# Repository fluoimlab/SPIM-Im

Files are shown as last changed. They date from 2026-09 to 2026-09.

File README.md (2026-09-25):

Stand With Ukraine (https://stand-with-ukraine.pp.ua)

Selective Plane Illumination Microscope
================================

_Fluorescence Imaging Laboratory, Kyiv, Ukraine_

<p align="center">
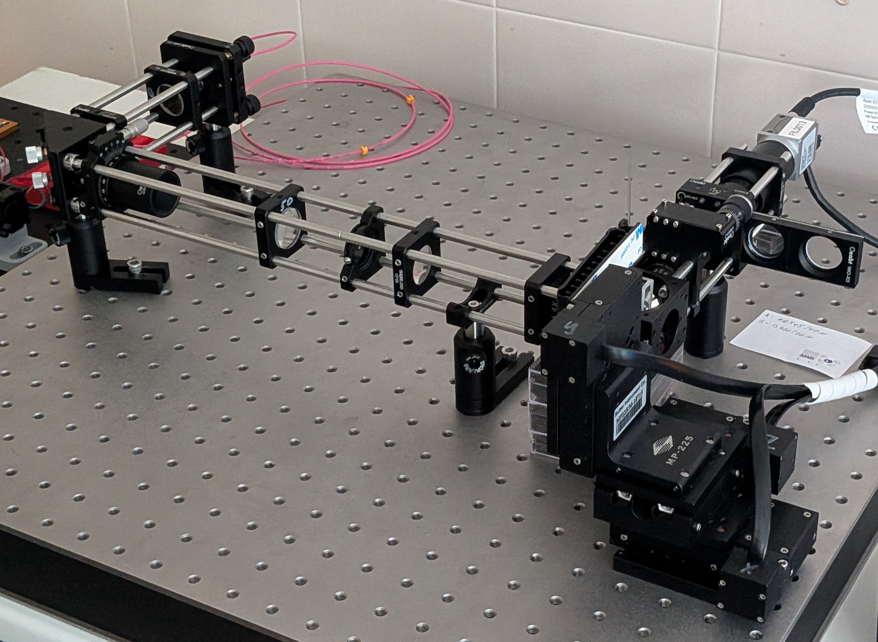
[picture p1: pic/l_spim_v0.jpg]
</a>
</p>
__L-SPIM v0__

# L-SPIM v0 parameters overview

| Parameter | Value |
| --- | --- |
| Detection objective | Olympus PlaN 10x 0.25 |
| Magnification | 5.56x (F100) or 6.94x (F125) |
| Camera | Basler Ace 2R Pro (a2A5320-23umPRO), 5320x3032 px (16.1 Mpx) |
| Pixel size | 0.493 μm/px (F100) or 0.395 μm/px (F125) |
| Field of view | 2.62x1.49 mm (F100) or 2.1x1.2 mm (F125) |
| Z-stack step resolution | 16 μstep/μm (0.0625 μm/μstep) |
| Lateral resolution, FWHM theoretical/estimated | 1.12 μm/2.06 μm |
| Axial resolution, FWHM theoretical/estimated | 11.70 μm/ 6.32 μm |
| Excitation lasers | 510 nm, 640 nm |
| Emission filters | Chroma HQ545/40m, Chroma D620/20m, Chroma HQ700/75m |

# Detection arm

## Detection params
| Parameter | Value |
| --- | --- |
| Detection objective | Olympus PlaN 10x 0.25 FN 22 (F18) |
| Detection tube lens | F100 or F125 |
| Magnification | 5.56x or 6.94x |
| Camera | Basler Ace 2R Pro (a2A5320-23umPRO) |
| Pixel size | 0.493 μm/px or 0.395 μm/px |
| Field of view | 2.62x1.49 mm or 2.1x1.2 mm |
| Theoretical resolution (500 nm) | 1.220 μm |
| Theoretical depth of field (500 nm, n=1.33) | 10.640 μm |
| Estimated resolution FWHM (F100) | 2.06 μm |
| Estimated depth of field FWHM (F100) | 6.32 μm |
| Z-stack step (Sutter Instruments MPC-200 with MP225/M) | 0.0625 μm/μstep (16 μstep/μm) |

## Filters

# Excitation arm
## Light path
Illumination objective 4x (F45)

Full FOV light sheet parameters:
- __Tubus lens F125__
FOV high 2.1 mm => d = 2.1 => $NA_{ill}$ = d / 2f = 2.1/(2*45) = 0.023

$x_{ls} \approx \frac{2 n \lambda}{\pi NA_{ill}^2} = \frac{2 * 1.33 * 510}{3.14 * 0.023^2} = 817 \mu m$

$z_{ls} \approx \frac{2 \lambda}{\pi NA_{ill}} = \frac{2 * 510}{3.14 * 0.023} = 14.1 \mu m$

## Lasers power

- 510 nm: 2.2 mW in imaging chamber
- 640 nm: 1.2 mW in imaging chamber

# Control software
## Micromanager configuration

## Camera
| Model | Basler Ace 2R |
| --- | --- |
| ID | a2A5320-23umPRO |
| Sensor | Sony IMX542 (CMOS) |
| Sensor size | 14.58x8.31 mm (1.1") |
| Sensor diagonal | 16.78 mm |
| Pixels (HxV) | 5320x3032 (16.1 Mpx) |
| Pixel size | 2.74x2.74 μm |
| Frame rate | up to 24 fps |

### GPIO pinout

|Pin|Function|I/O Line|Colour|
|-|-|-|-|
|1|12–24 VDC camera power|-|Brown|
|2|Opto-coupled I/O input line|Line 1|White|
|3|Ground for opto-coupled I/O line|-|Blue|
|4|General purpose I/O (GPIO) line|__Line 2__|Black|
|5|General purpose I/O (GPIO) line|Line 3|Grey|
|6|Ground for camera power and General Purpose I/O (GPIO) lines|-|Pink|

[Basler Power-I/O Cable](https://docs.baslerweb.com/basler-power-io-cable-m8-6p-open-p)

### GPIO configuration
Pylon Viewer v7.2 camera parameters, category __Digital I/O Control__:

- __Line Selector:__ Line 2
- __Line Inverter:__ not selected
- __Line Mode:__ Output
- __Line Source:__ Exposure Active

<p align="center">
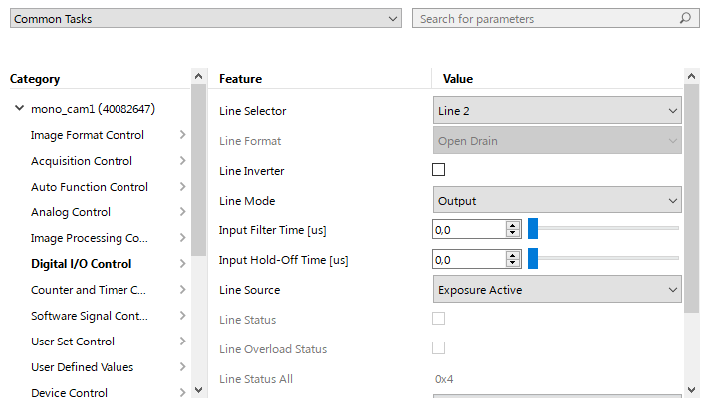
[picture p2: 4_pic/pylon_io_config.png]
</a>
</p>

## Sync
### ArdiunoMM
- Bauderate: 57600
- Responce timeout: 2000 ms

### Arduino32Bit (deprecated)
Synchronisation with [Arduino32bitBoards](https://micro-manager.org/Arduino32bitBoards), specs for ESP32:

- Baudrate: 115200
- Laser TTL trigger module requires 5V, need level conversion 3.3V -> 5V

__Pinout:__
- Trigger: __Pin 5 - camera Line 2 input__
- Channel 1 (index 0): __Pin 25/DAC - Level Converter ON__
- Channel 2 (index 1): __Pin 26/DAC - 510 nm trigger__
- Channel 3 (index 2): __Pin 27/PWM - 640 nm trigger__
- Channel 4 (index 3): Pin 15/PWM
- Channel 5 (index 4): Pin 14/PWM
- Channel 6 (index 5): Pin 4/PWM
- Channel 7 (index 6): Pin 23/PWM
- Channel 8 (index 7): Pin 19/PWM

__Decimal switch state value for ON is 2^index.__

__Switch states__
|State|Pin Hight|State|
|-|-|-|
|Level Converter ON|25|1|
|510 nm|25+26 (Ch.1+Ch.2)|1+2=__3__|
|640 nm|25+27 (Ch.1+Ch.3)|1+4=__5__|
|510 nm + 640 nm|25+26+27 (Ch.1+Ch.2+Ch.3)|1+2+4=__7__|

# License 
This open-source project is released under the CERN Open Hardware License. Our aims are to promote open scientific hardware development and to share our engineering solutions.

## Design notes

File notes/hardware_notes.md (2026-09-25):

# Hardware notes
- ESP32 with [Arduino32bitBoards device adapter](https://github.com/bonnom/Arduino32BitBoards/tree/master?tab=readme-ov-file)
- OXLaser 510 nm 50 mW, and 620 nm 100 mW
- Basler Ace 2R Pro / Pointgrey Grasshopper 3

## Illumination light path parameters

## Detection objectives

| Model | Olympus PlaN | Olympus UPlanFl Ph. 1 |
| --- | --- | --- |
| Magnification (M) | 10x | 10x |
| Numerical aperture (NA) | 0.25 | 0.3 |
| Working distance (WD) | 10.6 mm | 10 mm |
| Focal distance (F) | 18 mm | 18 mm |
| Back focal plane distance (BFP) | N/A | -19.1 mm |
| Field number (FN) | 22 | 26.5 mm |
| Lateral resolution | 1.34 μm | 1.12 μm |
| Parafocal distance (PD) | 45 mm | 65 mm |
| Exit pupil diameter (EP) | 9 mm | 10.8 mm |

## Cameras

| Model | FLIR Grasshopper 3 | Basler Ace 2R |
| --- | --- | --- |
| ID | GS3-U3-23S6M-C | a2A5320-23umPRO |
| Sensor | Sony IMX174 (CMOS) | Sony IMX542 (CMOS) |
| Sensor size | 11.25x7.03 mm (1/1.2") | 14.58x8.31 mm (1.1") |
| Sensor diagonal | 13.4 mm | 16.78 mm |
| Pixels (HxV) | 1920x1200 (2.3 Mpx) | 5320x3032 (16.1 Mpx) |
| Pixel size | 5.86x5.85 μm | 2.74x2.74 μm |
| Frame rate | up to 162 fps | up to 24 fps |

__FLIR Grasshopper 3 GPIO pinout__
<p align="center">
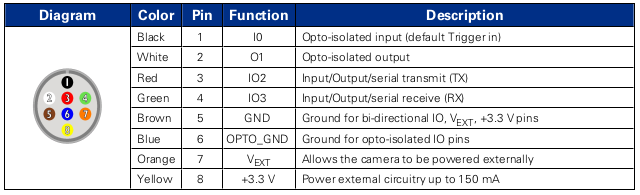
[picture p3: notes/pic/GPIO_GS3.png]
</a>
</p>

__Basler Ace 2R  GPIO pinout__
<p align="center">
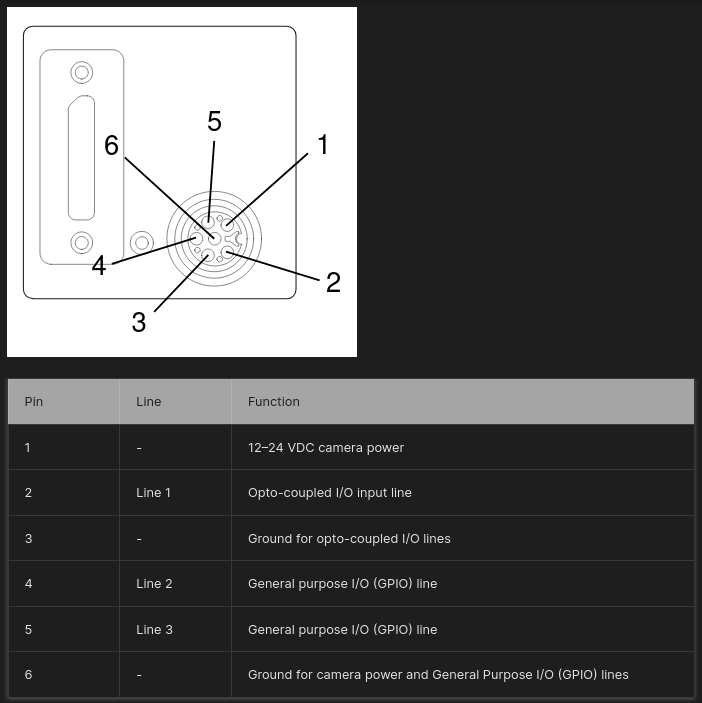
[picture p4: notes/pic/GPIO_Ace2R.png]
</a>
</p>

# Software
All control is provided with [Micro-Manager](https://micro-manager.org/) and [pymmcore-plus](https://pymmcore-plus.github.io/pymmcore-plus/) library with [napari-micromanager](https://pymmcore-plus.github.io/napari-micromanager/) GUI.

__Configuration__
| Component | Desctiption | Micro-manager adapter | Port (laptop)  | Note |
| --- | --- | --- | --- | --- |
| Camera | FLIR Grasshopper3 USB3 | [Point Grey Research](https://micro-manager.org/Point_Grey_Research) | USB 3.0 (COM7) | |
| Stage | Sutter Instruments MPC-200 | [CustomArduino](https://micro-manager.org/CustomArduino) (MarzhauserLStep Z-stage) | | |
| Lasers | Laser control wtih TTL | [Arduino](https://micro-manager.org/Arduino) | COM6 | Change ArduMM version in sketch to 2 |

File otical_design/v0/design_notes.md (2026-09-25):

# Design notes

> [!TIP]
> Read more about the SPIM principles: 
>
> - [Selective Plane Illumination Microscopy](https://link.springer.com/chapter/10.1007/978-0-387-45524-2_37)
> - [openSPIM project](https://openspim.org/)
> - [Selective plane illumination microscopy techniques in developmental biology](https://journals.biologists.com/dev/article/136/12/1963/65234/Selective-plane-illumination-microscopy-techniques)
> - [Using tissue clearing and light sheet fluorescence microscopy for the three-dimensional analysis of sensory and sympathetic nerve endings that innervate bone and dental tissue of mice](https://onlinelibrary.wiley.com/doi/full/10.1002/cne.25582)
> [Olarte et al., 2018](https://opg.optica.org/aop/fulltext.cfm?uri=aop-10-1-111&id=381035)
> [Power and  Huisken, 2017](https://whttps://opg.optica.org/aop/fulltext.cfm?uri=aop-10-1-111&id=381035ww.nature.com/articles/nmeth.4224)

## Gaussian litgh sheet

### Gaussian beam
__Focusing of a Gaussian beam__ (_Power and  Huisken, 2022_)
<p align="center">
</a>
</p>

In paraxial approximation:

```math
\sin \theta \approx \tan \theta \approx \theta
```

Accordng this approximation numerical aperture is equal:
```math
NA = n \sin \theta \approx n \theta 
```

Or for air:
```math
NA = \theta \simeq \frac{d_{beam}}{2 f}
```

The Rayleigh range of the beam and beam waist:

```math
\omega (x_R) = \sqrt{2} \omega_0
```

```math
x_R = \frac{\pi \omega_{0}^{2}}{\lambda}
```

Static light sheet thickness:

```math
\theta = \frac{\pi \omega_{0}}{\lambda} \Rightarrow  \omega_0 = \frac{2 f \lambda}{\pi d_{beam}} \Rightarrow z_{ls} = 2 \omega_0 = \frac{4 f \lambda}{\pi d_{beam}}
```

Static light sheet length:

```math
x_R = \frac{\pi \omega_{0}^{2}}{\lambda} \Rightarrow x_R = \frac{4 f^2 \lambda}{\pi d_{beam}^2} \Rightarrow x_{ls} = 2 x_{R} = \frac{8 f^2 \lambda}{\pi d_{beam}^2}
```

### Illumination system
__Relayed generation of a well-corrected static light sheet__ (_Huisken et al., 2004_)
<p align="center">
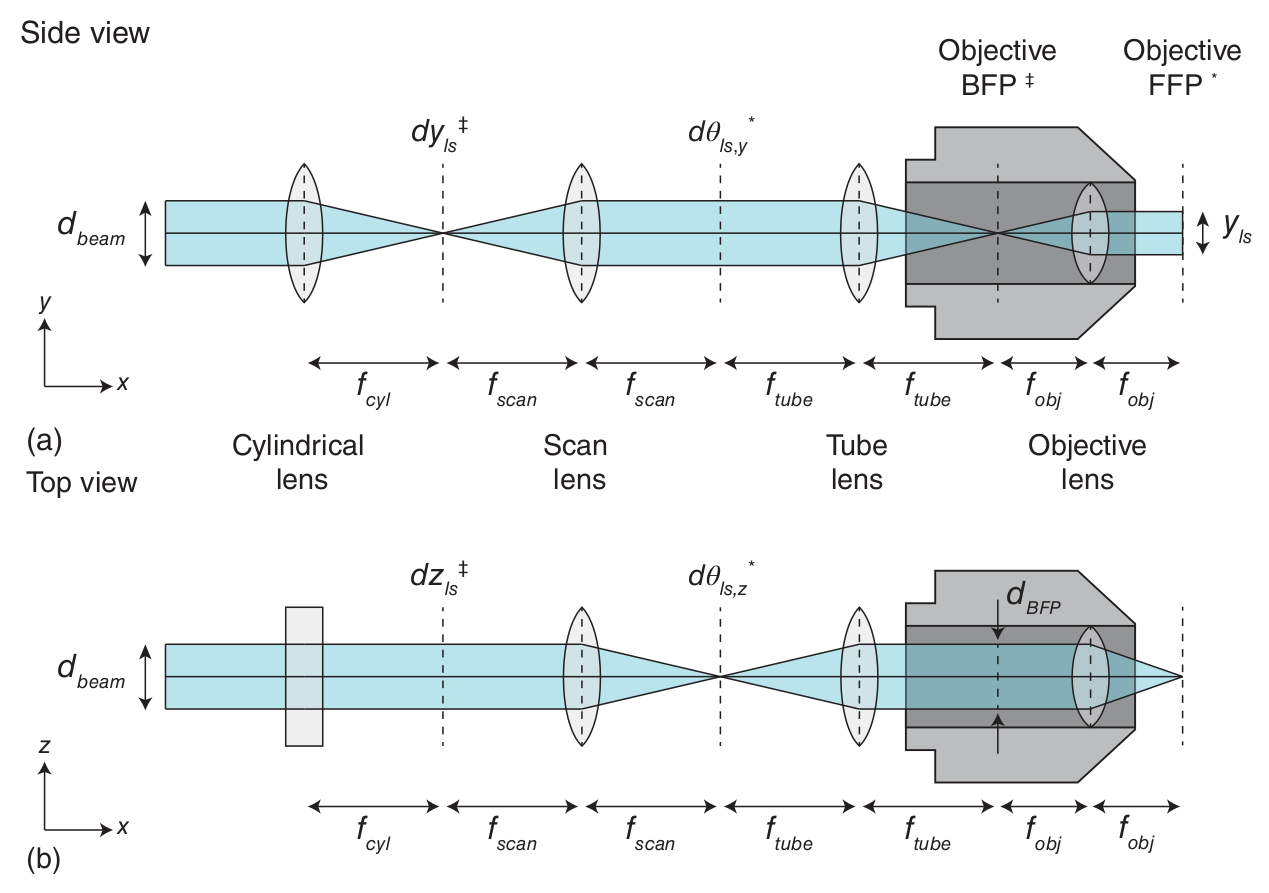
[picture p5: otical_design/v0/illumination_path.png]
</a>
</p>

Objective focal length ($f_{ref}$ for Olympus 180 mm):

```math
f_{front} = n_{imm} f_{back}
```

```math
f_{obj} = f_{back} = \frac{f_{ref}}{M}
```

```math
d_{BFP} = d_{beam} \frac{f_{tube}}{f_{scan}}
```

Illumination NA:

```math
NA_{ill} = n_{imm} \theta = \frac{d_{beam} n_{imm}}{2 f_{front}} = \frac{d_{beam}}{2 f_{obj}}
```

Static light sheet parameters:

```math
z_{ls} = \frac{2 \lambda}{\pi NA_{ill}}
```

```math
x_{ls} = \frac{2 n_{imm} \lambda}{\pi NA_{ill}^2}
```

Relay system:

```math
\textbf{Z}_{ls} = z_{ls} \frac{f_{scan}}{f_{tube}} =  \frac{4 f_obj \lambda}{\pi d_{beam}} \cdot \frac{f_{scan}}{f_{tube}}
```

```math
\textbf{X}_{ls} = x_{ls} (\frac{f_{scan}}{f_{tube}})^2 = \frac{8 f_{obj}^2 n_{imm} \lambda}{\pi d_{beam}^2} \cdot (\frac{f_{scan}}{f_{tube}})^2
```

```math
\textbf{Y}_{ls} = \frac{f_{scan}}{f_{cyl}} \frac{f_{obj}}{f_{tube}} d_{beam}
```

## Detection arm
Lateral resolution (Rayleigh criterion):

```math
d_{xy} = \frac{0.61 \cdot \lambda_{det.}}{NA_{det.}}
```

Axial resolution (depth of field/DOF):

```math
d_z = \frac{n \cdot \lambda_{det.}}{NA_{det.}^2}
```

# Samples and desired characteristics

__NB: is 10x NA 0.25 FN 22 enough?__

## Sciatic nerve
- Nerve diameter: 1.5-2 mm
- Nerve length: 5-20 mm
- A-fiber diameter: 1.5 - 10 um 
- C-fiber diameter: 0.5 - 2 um
- Minimal vessel diameter

## Scaffolds
_In progress_

## Characteristics
- FOV ~ 1x2 mm
- Lateral resolution <1.5 um

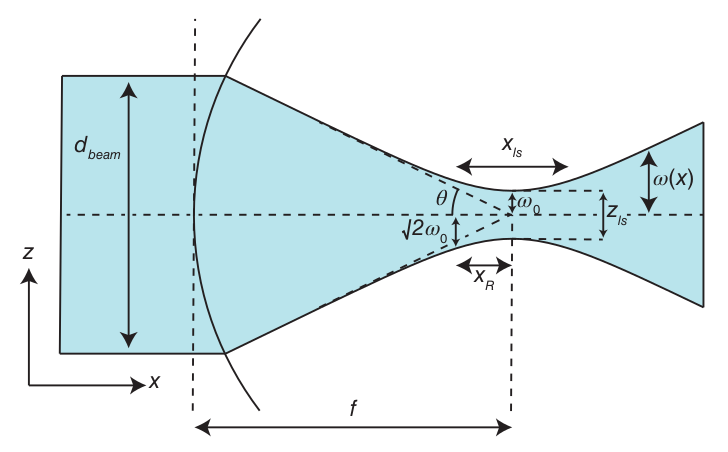
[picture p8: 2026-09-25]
notes/pic/gaussian_beam.png

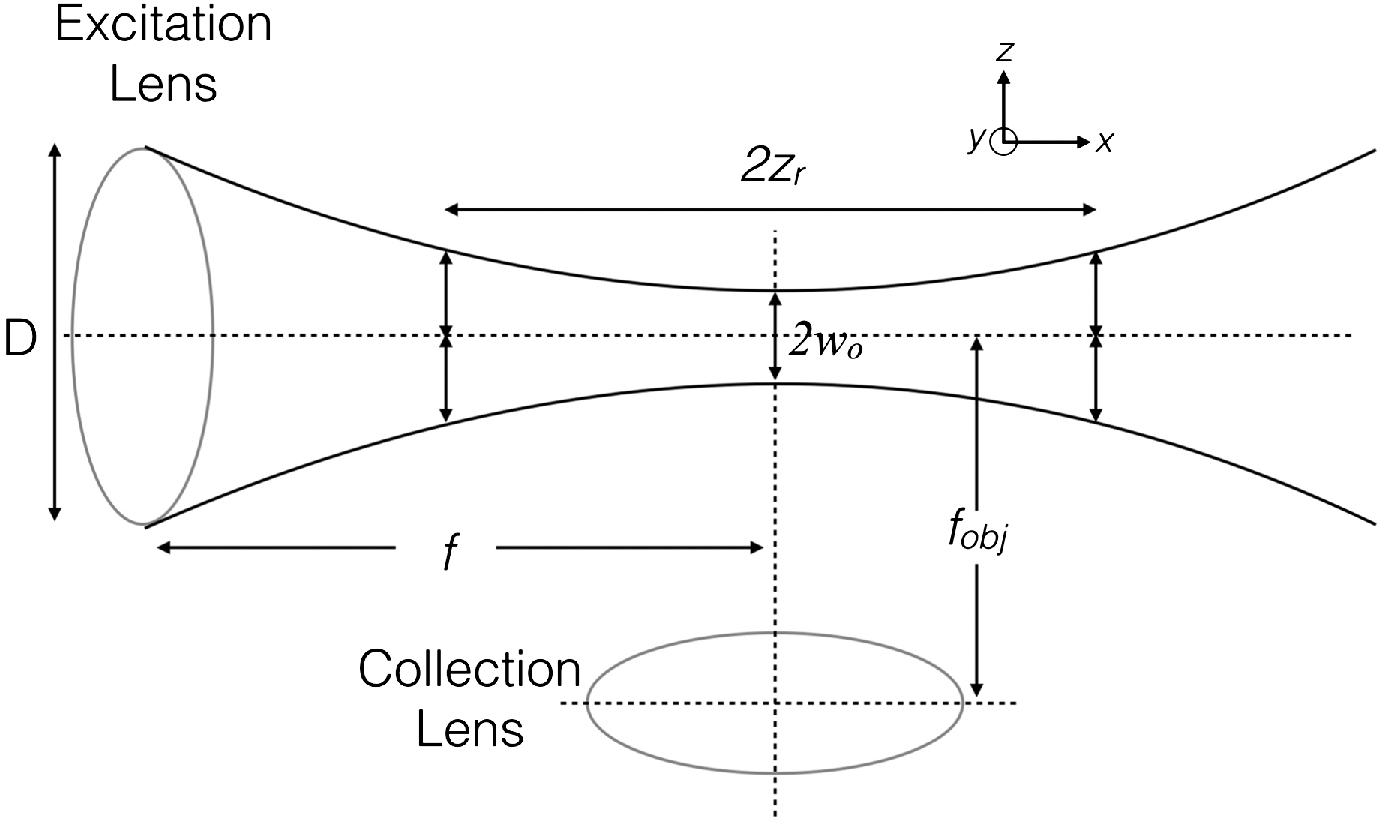
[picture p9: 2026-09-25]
notes/pic/ls_geom_olarte2017.jpeg

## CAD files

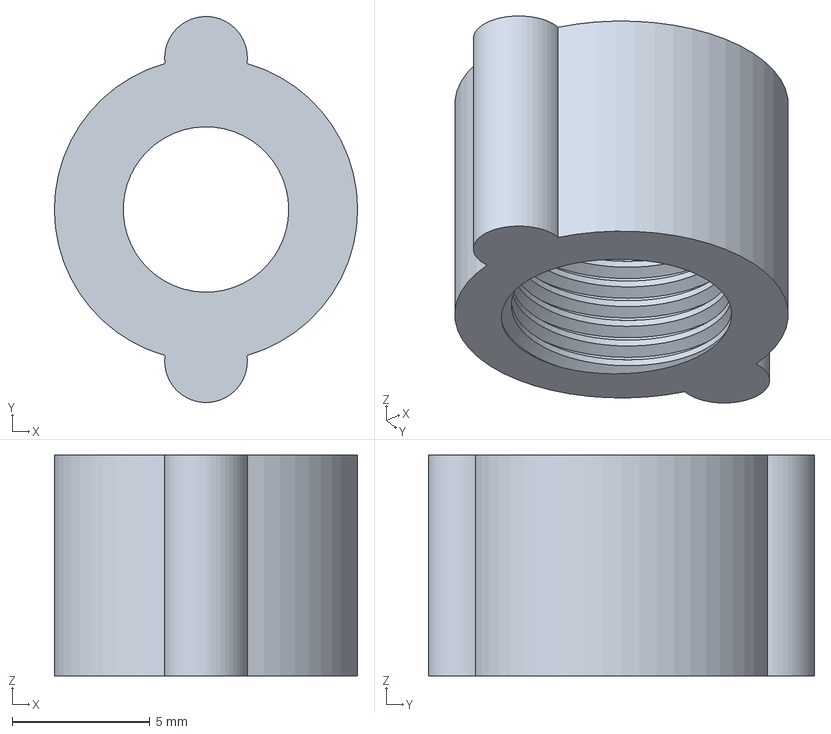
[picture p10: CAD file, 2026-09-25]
models_3D/FC_colimator/FC_single_lens_colimator_v0.FCStd
11.0 x 14.0 x 8.00 mm

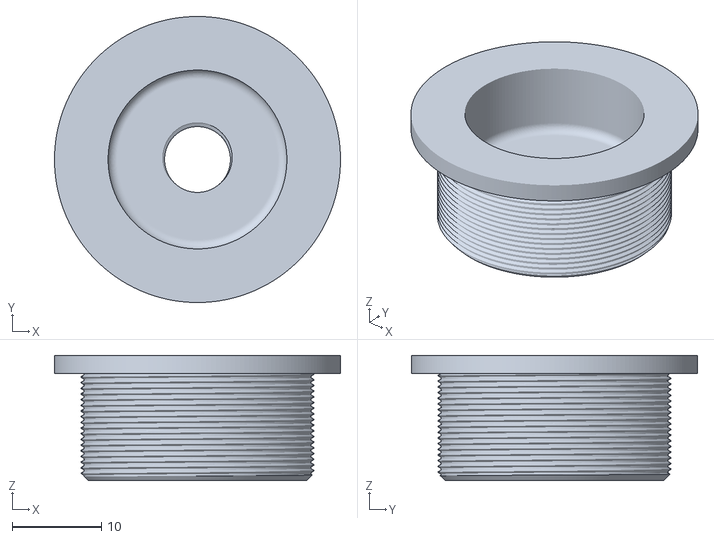
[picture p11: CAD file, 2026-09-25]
models_3D/FC_to_SM1_adapter/Sm1toM8_tolerance04.stl
32.0 x 32.0 x 14.0

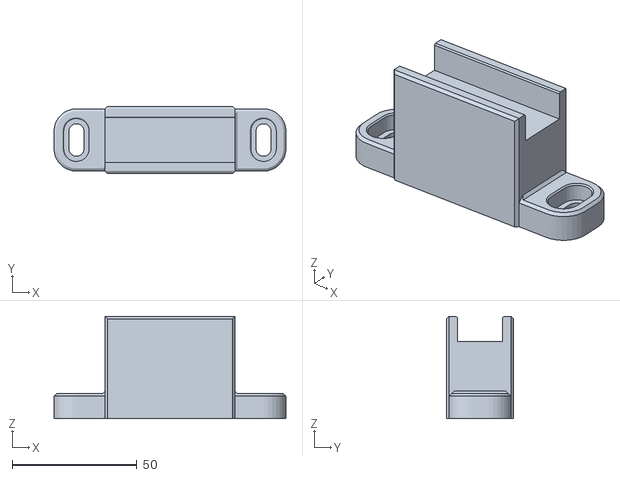
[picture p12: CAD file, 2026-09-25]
models_3D/laser_combiner/0_h40mm_combiner/v2/laserland_620_100mW_h40_25mm_M6_board_v2.stl
93.0 x 27.0 x 41.0

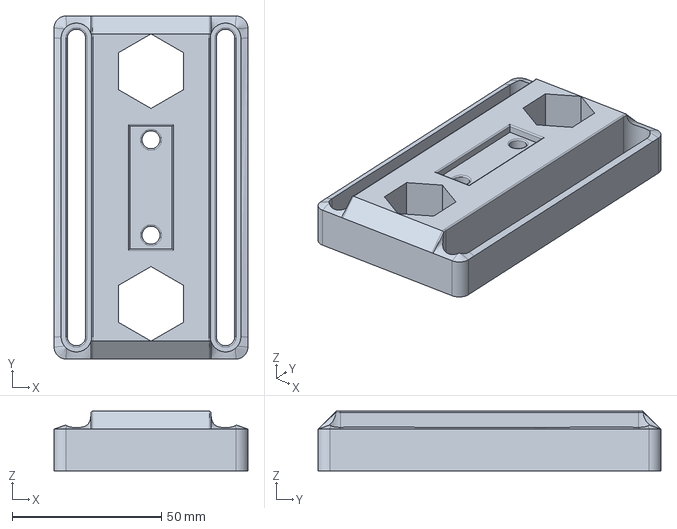
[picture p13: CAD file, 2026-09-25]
models_3D/laser_combiner/breadboard_platform/25mm_M6_platform_v0.FCStd
65.0 x 115.0 x 20.0 mm

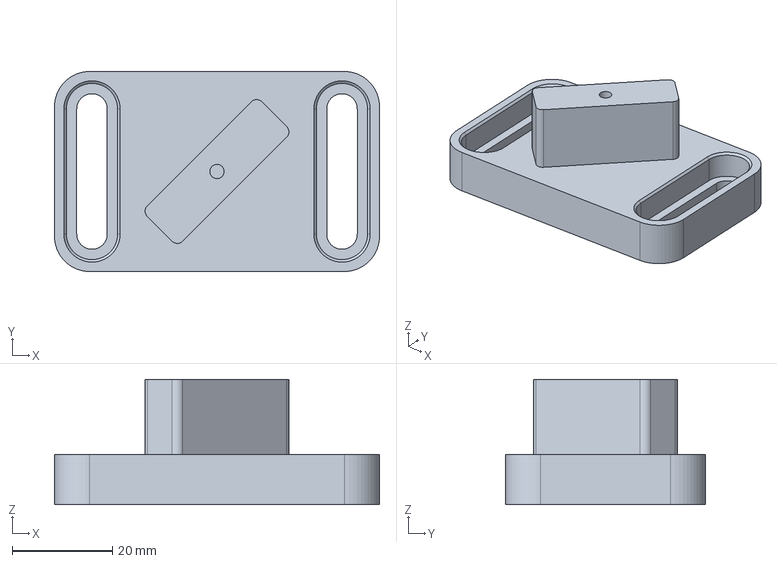
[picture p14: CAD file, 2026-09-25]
models_3D/laser_combiner/kinematic_stand/25mm_M6_stand_v0.FCStd
65.0 x 40.0 x 25.0 mm

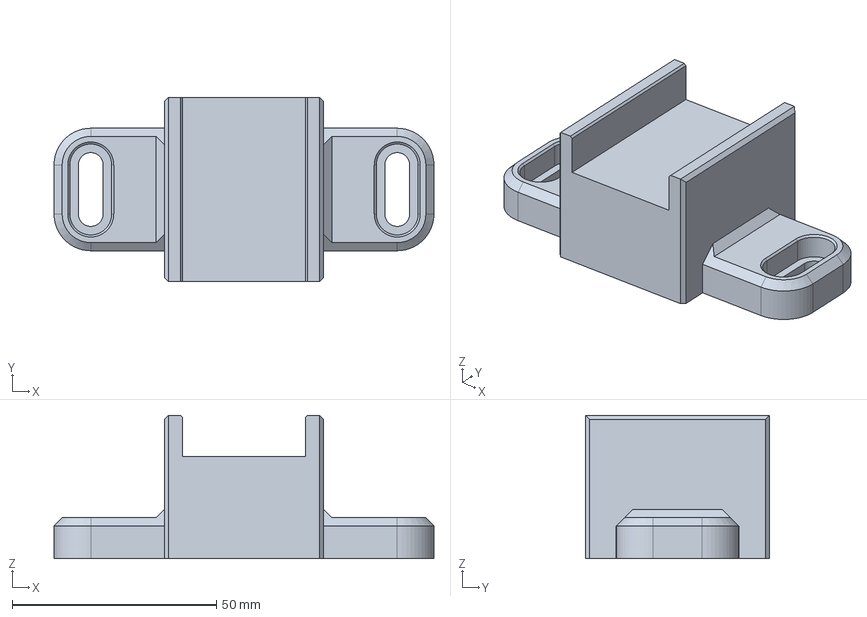
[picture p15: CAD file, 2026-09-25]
models_3D/laser_combiner/laser_breadboard_mount/specific_models/laserland_510nm_50mW_25mm_M6_board_v1.FCStd
93.0 x 45.0 x 35.0 mm

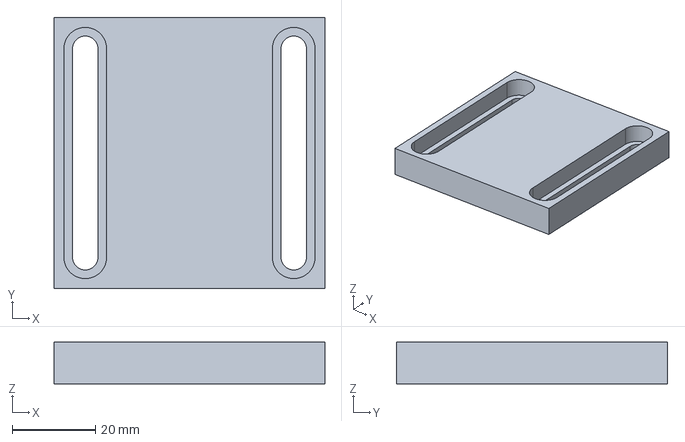
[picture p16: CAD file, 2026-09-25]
models_3D/laser_combiner/laser_combiner_colimator_stand/colimator_stand.FCStd
65.0 x 65.0 x 10.0 mm

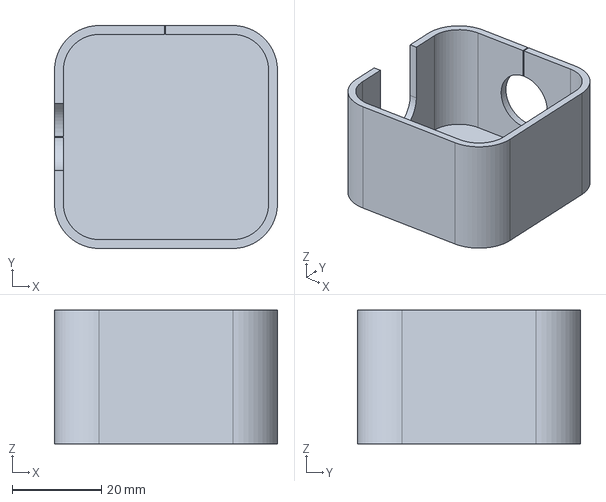
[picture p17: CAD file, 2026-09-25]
models_3D/laser_combiner/laser_combiner_cover/laser_combiner_cover_v1.FCStd
50.0 x 50.0 x 30.0 mm

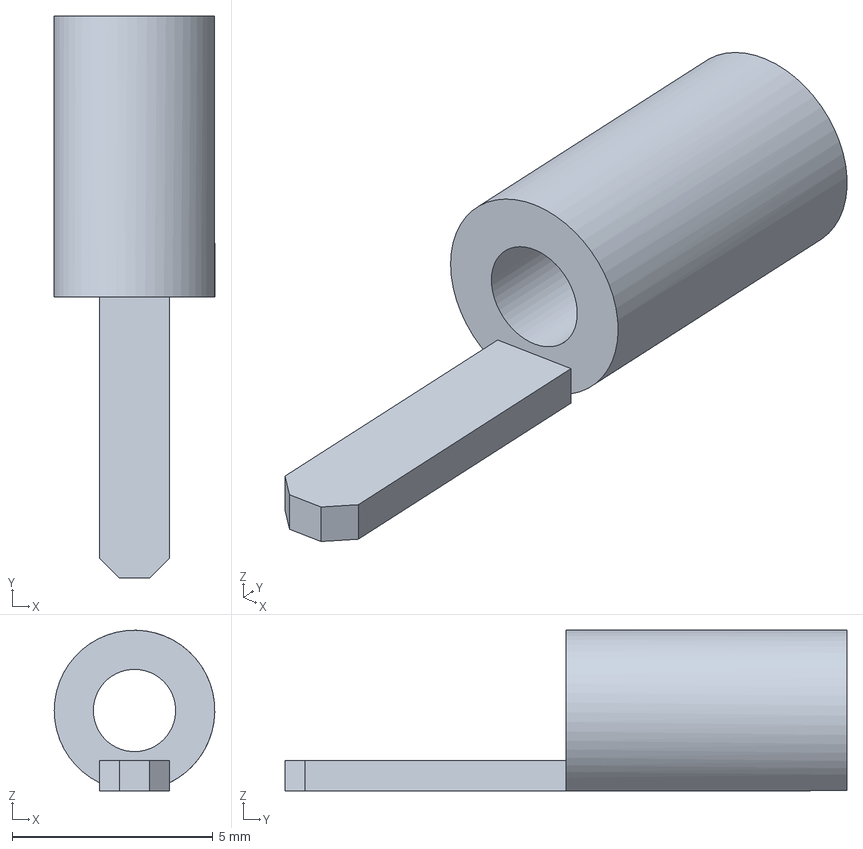
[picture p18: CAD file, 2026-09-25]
models_3D/sample_mounts/simple_narrow_20rod_v0.FCStd
4.00 x 14.0 x 4.00 mm

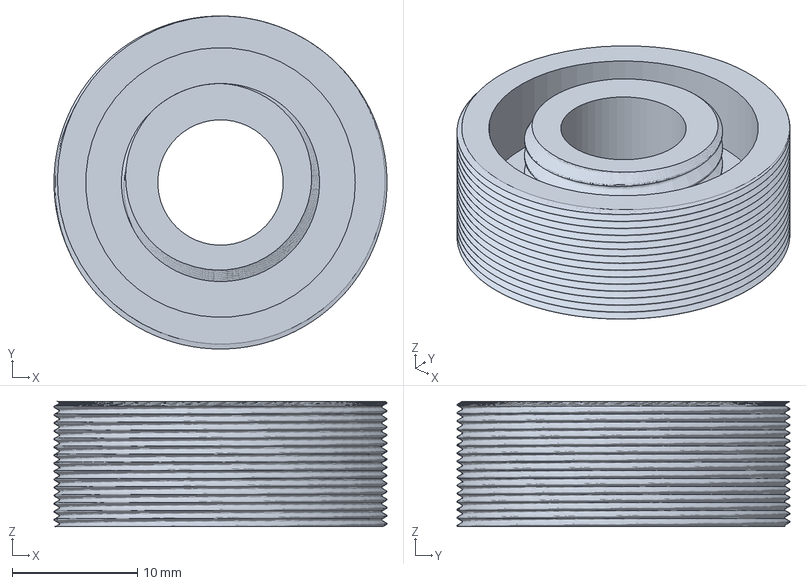
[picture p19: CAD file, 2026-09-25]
models_3D/threads/SM1.FCStd
26.6 x 26.6 x 10.0 mm

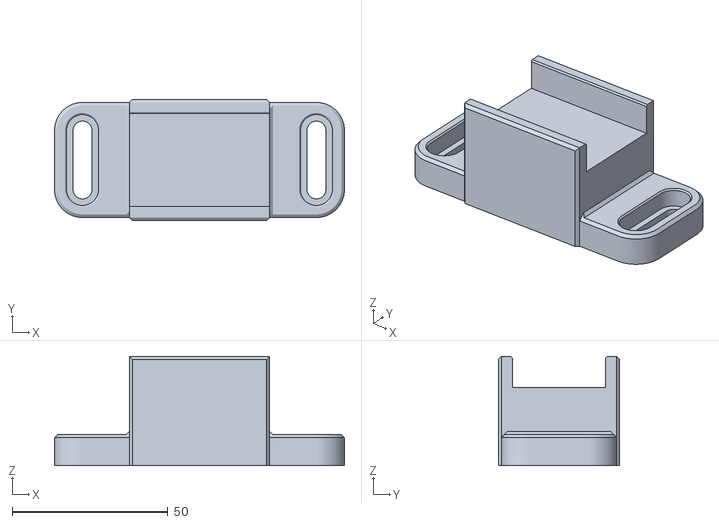
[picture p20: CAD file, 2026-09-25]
models_3D/laser_combiner/0_h40mm_combiner/v2/laserland_510_50mW_h40_25mm_M6_board_v2.stl
93.0 x 38.9 x 35.0

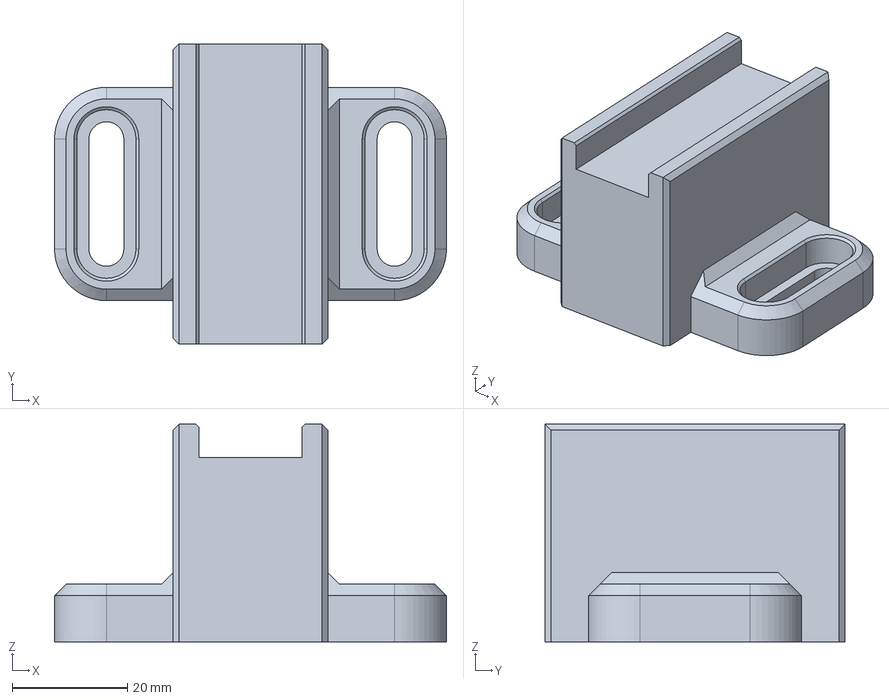
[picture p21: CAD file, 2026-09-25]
models_3D/laser_combiner/laser_breadboard_mount/specific_models/laserland_640nm_100mW_25mm_M6_board_v1.FCStd
68.0 x 52.0 x 37.8 mm

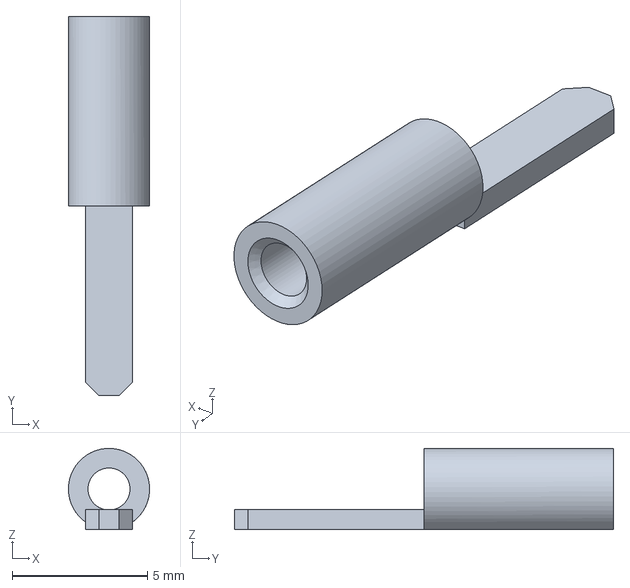
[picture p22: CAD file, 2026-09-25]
models_3D/sample_mounts/simple_narrow_15rod_v0.FCStd
3.00 x 14.0 x 3.00 mm

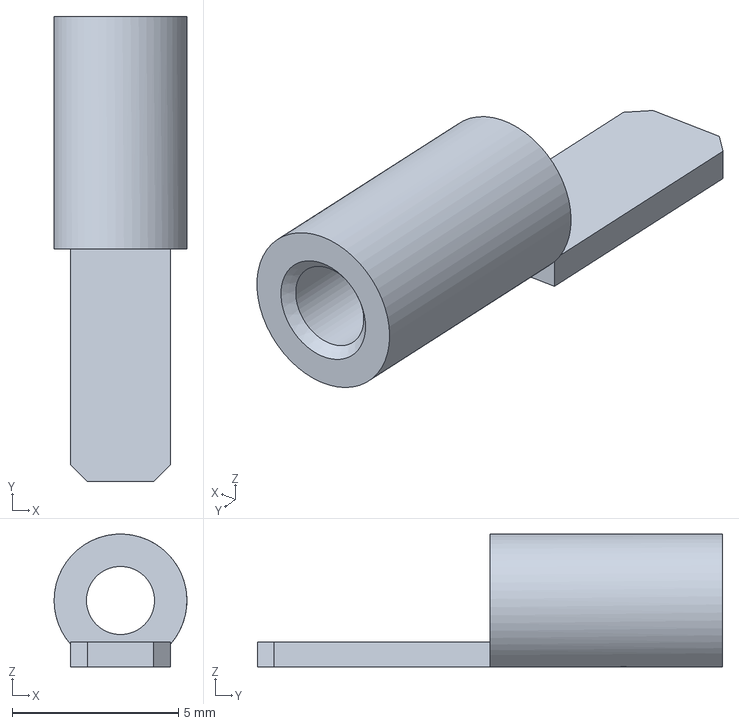
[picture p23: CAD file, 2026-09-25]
models_3D/sample_mounts/simple_20rod_v0.FCStd
4.00 x 14.0 x 4.00 mm

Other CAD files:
models_3D/laser_combiner/laser_combiner_cover/laser_combiner_cover_v1-Body.stl
models_3D/laser_combiner/0_h40mm_combiner/v2/colimator_mount_25mm_M6_platform_v0.stl
models_3D/laser_combiner/laser_breadboard_mount/25mm_M6_board_v2.FCStd
models_3D/laser_combiner/laser_breadboard_mount/specific_models/laserland_505nm_100mW_25mm_M6_board_v1.FCStd
models_3D/FC_colimator/FC_single_lens_colimator_v0.stl
models_3D/laser_combiner/0_h40mm_combiner/v1/dichro_25mm_M6_stand_v0-h40mm.stl
models_3D/laser_combiner/0_h40mm_combiner/v1/dichro_25mm_M6_stand_v1-h40mm.stl
models_3D/laser_combiner/0_h40mm_combiner/v1/laser_505nm_25mm_M6_board_v1-h40.stl
models_3D/laser_combiner/0_h40mm_combiner/v1/laser_510nm_25mm_M6_board_v1-h40mm.stl
models_3D/laser_combiner/0_h40mm_combiner/v1/laser_640nm_25mm_M6_board_v1-h40mm.stl
models_3D/laser_combiner/laser_breadboard_mount/25mm_M6_board_v0.FCStd
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

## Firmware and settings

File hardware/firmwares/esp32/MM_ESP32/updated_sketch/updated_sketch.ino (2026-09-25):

// This is the DAC blanking sketch
// The digital output channels 7 and 8 are replaced with CH1 and CH2
// The voltages for are set in the same way as for other sketches that use a DAC

/*
   First, a serial command can directly set the digital output patern

   Second, a series of patterns can be stored in the arduino and a trigger on pin 2
      wil trigger the consecutive pattern (trigger mode).

   Third, intervals between consecutive patterns can be specified and paterns will be
   generated at these specified time points (timed trigger mode).
*/

/*Interface specifications
    Digital pattern specification: single byte, bit 0 corresponds to pin 8,
      bit 1 to pin 9, etc.. Bits 7 and 8 will not be used (and should stay 0).
*/

/* Set digital output command: 1p
    Where p is the desired digital pattern.

    Controller will return 1 to indicate succesfull execution.
*/

/* Get Digital output command: 2

    Controller will return 2p. Where p is the current digital output pattern
*/

/* Digital output command 3xvv
      Where x is the ouput channel and vv is the output in
      a 12-bbit significant number.

      Controller will return 3xvv
*/

/* Get analogue output: 4
*/

/* Set digital pattern for triggerd mode: 5xd
      Where x is the number of the pattern (currrently, 12 patterns can be stored).
      and d is the digital pattern to be stored at that position. Note that x should be
      real number (i.e., not ASCI encoded)

      Controller will return 5xd
*/

/* Set the Number of digital patterns to be used: 6x
     Where x indicates how many digital patterns will be used (currently, up to 12
     patterns maximum).  In triggered mode, after reaching this many triggers,
     the controller will re-start the sequence with the first pattern.

     Controller will return 6x
*/

/* Skip tirgger: 7x
      Where x indicates how many digital change events on the trigger input pin
      will be ignored.

      Controller will respond with 7x
*/

/* Start trigger mode: 8
      Controller will return 8 to indicate start of trigger mode
      Stop triggered at 9. Trigger mode will supersede (but not stop)
      blanking mode (if it was active)
*/

/* Stop Trigger mode: 9
      Controller will return 9x where x is the number of triggers received during the last
      trigger mode run
*/

/* Set time interval for timed trigger mode: 10xtt
      Where x is the number interval (currently 12 intervals can be stored)
      and tt is the interval (in ms) in Arduino unsigned int format.

      Controller will return 11x
*/

/* Sets how often the timed pattern will be repeated 11x
      This value will be used in timed-trigger mode and sets how often the ouput
      pattern will be repeated.

      Controller will return 11x
*/

/* Starts timed trigger mode: 12
      In timed trigger mode, digital patterns as with function 5 will appear on the
      output pins with intervals (in ms) as set with function 10. After the number of
      patterns set with function 6, the pattern will be repeated for the number of times
      set with function 11. Any input character (which will be processed) will stop
      the pattern generation

      Controller will return 12.
*/

/* Start blanking mode: 20
      In blanking mode, zeroes will be written on the output pins when the trigger pin
      is low, when the trigger pin is high, the pattern set with command 1 will be
      applied to the output pins.

      Controller will return 20
*/

/* Stop blanking mode: 21
      Stopts blanking mode

      Controller returns 21
*/

/* Get Identifcatio: 30
       Returns in ASCI MM-Ard\r\n
*/

/* Get Version: 31
      Returns: version number in ASCI \r\n
*/

/* Read digital state of analog input pins 0-5: 40
      Returns raw value of PINC
*/

/* Read analog state of input pins 0-5: 41x
      x=0-5. Returns analog value as a 10-bit number (0-1023)
*/

/*
   Possible extensions:
     Set and Get Mode (low, change, rising, falling) for trigger mode
     Get digital patterm
     Get Number of digital patterns
*/

unsigned int version_ = 3;

// pin on whick to receive the trigger (2 and 3 can be used with interrupts, although this code does not use them)
// to read out the state of inPin_ faster, ise
// int inPinBit_ = 1<< inPin_; // bit mask

/* TLV5618 configuration
  int dataPin  = 3; // DIN
  int clockPin = 4; // SLCK
  int latchPin = 5; // CS
*/

const int SEQUENCELENGTH = 12 ; //This should be good enough for everybody
byte triggerPattern_[SEQUENCELENGTH]       = {0, 0, 0, 0, 0, 0, 0, 0, 0, 0, 0, 0};
unsigned int triggerDelay_[SEQUENCELENGTH] = {0, 0, 0, 0, 0, 0, 0, 0, 0, 0, 0, 0};
int patternLength_  = 0;
byte repeatPattern_ = 0;
volatile long triggerNr_; // total # of triggers in this run (0-based)
volatile long sequenceNr_; // # of trigger in sequence (0-based)
int skipTriggers_ = 0; // # of triggers to skip before starting to generate patterns
byte currentPattern_ = 0;
const unsigned long timeOut_ = 1000;
bool blanking_ = false;
bool blankOnHigh_ = false;
bool triggerMode_ = false;
boolean triggerState_ = false;


// New additions for rewrite code
byte portbAlt = 0;
byte pindAlt = 0;

// Set the output channnels, these are the ones for most handy for TinyPico
const int inPin_ = 5;
const int ch1 = 25;
const int ch2 = 26;
const int ch3 = 27;
const int ch4 = 15;
const int ch5 = 14;
const int ch6 = 4;
const int ch7 = 23;
const int ch8 = 19;

// Set the input channels for future use
const int a1 = 18;
const int a2 = 22;
const int a3 = 21;
//  const int a4 = 0;
//  const int a5 = 4;


// New additions for use of internal DAC
unsigned int msblsb[] = {255, 255, 255, 255, 255, 255, 255, 255};


// New Additions for use PWM
const int PWMfreq = 10000;
const int PWMresolution = 8;
// const int pwmCh3 = 2;
// const int pwmCh4 = 3;
// const int pwmCh5 = 4;
// const int pwmCh6 = 5;
// const int pwmCh7 = 6;
// const int pwmCh8 = 7;


void setup() {
  // put your setup code here, to run once:
  Serial.begin(115200); //Baud rate

  pinMode(inPin_, INPUT);

  // Setting up pwm
  // ledcAttach(pwmCh3, PWMfreq, PWMresolution);
  // ledcAttach(pwmCh4, PWMfreq, PWMresolution);
  // ledcAttach(pwmCh5, PWMfreq, PWMresolution);
  // ledcAttach(pwmCh6, PWMfreq, PWMresolution);
  // ledcAttach(pwmCh7, PWMfreq, PWMresolution);
  // ledcAttach(pwmCh8, PWMfreq, PWMresolution);

  // ledcAttach(ch3, pwmCh3);
  // ledcAttach(ch4, pwmCh4);
  // ledcAttach(ch5, pwmCh5);
  // ledcAttach(ch6, pwmCh6);
  // ledcAttach(ch7, pwmCh7);
  // ledcAttach(ch8, pwmCh8);

  ledcAttach(ch3, PWMfreq, PWMresolution);
  ledcAttach(ch4, PWMfreq, PWMresolution);
  ledcAttach(ch5, PWMfreq, PWMresolution);
  ledcAttach(ch6, PWMfreq, PWMresolution);
  ledcAttach(ch7, PWMfreq, PWMresolution);
  ledcAttach(ch8, PWMfreq, PWMresolution);


  // Is disabled when PWM blanking
  /*
    pinMode(dataPin, OUTPUT);

    //pinMode(ch1, OUTPUT);
    //pinMode(ch2, OUTPUT); is disabled with DAC blanking
    pinMode(ch3, OUTPUT);
    pinMode(ch4, OUTPUT);
    pinMode(ch5, OUTPUT);
    pinMode(ch6, OUTPUT);
  */

}

void loop() {
  // put your main code here, to run repeatedly:
  if (Serial.available() > 0)
  {
    int inByte = Serial.read();
    switch (inByte)
    {
      // Set digital output
      case 1: if (waitForSerial(timeOut_))
        {
          currentPattern_ = Serial.read();
          // Do not set bits 6 and 7 for Arduino Uno
          // currentPattern_ = currentPattern_ & B0011111;     Removed for additions of extra channels

          if (!blanking_)
          {
            portbAlt = currentPattern_;
            writePattern(currentPattern_);
          }
          Serial.write(byte(1));
        }
        break;

      // Get digital output
      case 2:
        Serial.write( byte(2));
        Serial.write( portbAlt);
        break;
      // Set Analogue output (TODO: save for 'Get Analogue output')
      //Not Implemented at the moment

      // DAC
      case 3:
        if (waitForSerial(timeOut_))
        {
          int channel = Serial.read();
          if (waitForSerial(timeOut_))
          {
            byte msb = Serial.read();
            msb &= B00001111;
            if (waitForSerial(timeOut_)) {
              byte lsb = Serial.read();
              msblsb[channel] = (int)lsb + (int)msb * 256;
              msblsb[channel] = msblsb[channel] / 16;
              if (channel == 0) {
                dacWrite(25, msblsb[channel]);

              }
              else if (channel == 1) {
                dacWrite(26, msblsb[channel]);
              }
              else {
                ledcWrite(channel, msblsb[channel]);
              }
              Serial.write( byte(3));
              Serial.write( channel);
              Serial.write(msb);
              Serial.write(lsb);
            }
          }
        }
        break;
      // Sets the specified digital pattern for triggered mode
      case 5:
        if (waitForSerial(timeOut_)) {
          int patternNumber = Serial.read();
          if ( (patternNumber >= 0) && (patternNumber < SEQUENCELENGTH) ) {
            if (waitForSerial(timeOut_)) {
              triggerPattern_[patternNumber] = Serial.read();
              // triggerPattern_[patternNumber] = triggerPattern_[patternNumber] & B00111111; Removed for additions extra channels
              Serial.write( byte(5));
              Serial.write( patternNumber);
              Serial.write( triggerPattern_[patternNumber]);
              break;
            }
          }
        }
        Serial.write( "n:");//Serial.print("n:");
        break;

      // Sets the number of digital patterns that will be used
      case 6:
        if (waitForSerial(timeOut_)) {
          int pL = Serial.read();
          if ( (pL >= 0) && (pL <= 12) ) {
            patternLength_ = pL;
            Serial.write( byte(6));
            Serial.write( patternLength_);
          }
        }
        break;

      // Skip triggers
      case 7:
        if (waitForSerial(timeOut_)) {
          skipTriggers_ = Serial.read();
          Serial.write( byte(7));
          Serial.write( skipTriggers_);
        }
        break;

      //  starts trigger mode
      case 8:
        if (patternLength_ > 0) {
          sequenceNr_ = 0;
          triggerNr_ = -skipTriggers_;
          triggerState_ = digitalRead(inPin_) == HIGH;
          portbAlt = writeZeros();
          Serial.write( byte(8));
          triggerMode_ = true;
        }
        break;

      // return result from last triggermode
      case 9:
        triggerMode_ = false;
        portbAlt = writeZeros();
        Serial.write( byte(9));
        Serial.write( triggerNr_);
        break;

      // Sets time interval for timed trigger mode
      // Tricky part is that we are getting an unsigned int as two bytes
      case 10:
        if (waitForSerial(timeOut_)) {
          int patternNumber = Serial.read();
          if ( (patternNumber >= 0) && (patternNumber < SEQUENCELENGTH) ) {
            if (waitForSerial(timeOut_)) {
              unsigned int highByte = 0;
              unsigned int lowByte = 0;
              highByte = Serial.read();
              if (waitForSerial(timeOut_))
                lowByte = Serial.read();
              highByte = highByte << 8;
              triggerDelay_[patternNumber] = highByte | lowByte;
              Serial.write( byte(10));
              Serial.write(patternNumber);
              break;
            }
          }
        }
        break;

      // Sets the number of times the patterns is repeated in timed trigger mode
      case 11:
        if (waitForSerial(timeOut_)) {
          repeatPattern_ = Serial.read();
          Serial.write( byte(11));
          Serial.write( repeatPattern_);
        }
        break;

      //  starts timed trigger mode
      case 12:
        if (patternLength_ > 0) {
          portbAlt = writeZeros();
          Serial.write( byte(12));
          for (byte i = 0; i < repeatPattern_ && (Serial.available() == 0); i++) {
            for (int j = 0; j < patternLength_ && (Serial.available() == 0); j++) {
              portbAlt = triggerPattern_[j];
              writePattern(triggerPattern_[j]);
              delay(triggerDelay_[j]);
            }
          }
          writeZeros();
        }
        break;

      // Blanks output based on TTL input
      case 20:
        blanking_ = true;
        Serial.write( byte(20));
        break;

      // Stops blanking mode
      case 21:
        blanking_ = false;
        Serial.write( byte(21));
        break;

      // Sets 'polarity' of input TTL for blanking mode
      case 22:
        if (waitForSerial(timeOut_)) {
          int mode = Serial.read();
          if (mode == 0)
            blankOnHigh_ = true;
          else
            blankOnHigh_ = false;
        }
        Serial.write( byte(22));
        break;

      // Gives identification of the device
      case 30:
        Serial.println("MM-Ard");
        break;

      // Returns version string
      case 31:
        Serial.println(version_);
        break;

      //Not implemented
      case 40:
        Serial.write( byte(40));
        //Serial.write( PINC);
        Serial.write( byte(0));
        break;

      case 41:
        if (waitForSerial(timeOut_)) {
          int pin = Serial.read();
          if (pin >= 0 && pin <= 5) {
            int val = analogRead(pin);
            Serial.write( byte(41));
            Serial.write( pin);
            Serial.write( highByte(val));
            Serial.write( lowByte(val));
          }
        }
        break;

      case 42:
        if (waitForSerial(timeOut_)) {
          int pin = Serial.read();
          if (waitForSerial(timeOut_)) {
            int state = Serial.read();
            Serial.write( byte(42));
            Serial.write( pin);
            if (state == 0) {
              digitalWrite(14 + pin, LOW);
              Serial.write( byte(0));
            }
            if (state == 1) {
              digitalWrite(14 + pin, HIGH);
              Serial.write( byte(1));
            }
          }
        }
        break;

    }
  }

  // In trigger mode, we will blank even if blanking is not on..
  if (triggerMode_) {
    pindAlt = digitalRead(inPin_);
    boolean tmp = pindAlt;
    if (tmp != triggerState_) {
      if (blankOnHigh_ && tmp ) {
        portbAlt = writeZeros();

      }
      else if (!blankOnHigh_ && !tmp ) {
        portbAlt = writeZeros();
      }
      else {
        if (triggerNr_ >= 0) {
          portbAlt = triggerPattern_[sequenceNr_];
          writePattern(triggerPattern_[sequenceNr_]);
          sequenceNr_++;
          if (sequenceNr_ >= patternLength_)
            sequenceNr_ = 0;
        }
        triggerNr_++;
      }

      triggerState_ = tmp;
    }
  } else if (blanking_) {
    if (blankOnHigh_) {
      if (! digitalRead(inPin_))
      {
        portbAlt = currentPattern_;
        writePattern(currentPattern_);
      }
      else
      {
        portbAlt = writeZeros();
      }
    }  else {
      if (! digitalRead(inPin_)) {
        portbAlt = writeZeros();
      }
      else  {
        portbAlt = currentPattern_;
        writePattern(currentPattern_);
      }
    }
  }
}

bool waitForSerial(unsigned long timeOut)
{
  unsigned long startTime = millis();
  while (Serial.available() == 0 && (millis() - startTime < timeOut) ) {}
  if (Serial.available() > 0)
    return true;
  return false;
}

byte writeZeros()
{
  dacWrite(25, 0);
  dacWrite(26, 0);
  ledcWrite(2, 0);
  ledcWrite(3, 0);
  ledcWrite(4, 0);
  ledcWrite(5, 0);
  ledcWrite(6, 0);
  ledcWrite(7, 0);
  return portbAlt = 0;
}

void writePattern(byte pattern_)
{
  if (bitRead(pattern_, 0) == 0)  // Added for DAC blanking
  {
    dacWrite(25, 0);
  }
  else {
    dacWrite(25, msblsb[0]);
  }

  if (bitRead(pattern_, 1) == 0) // Added for DAC blanking
  {
    dacWrite(26, 0);
  }
  else {
    dacWrite(26, msblsb[1]);
  }


  for (int i = 2; i <= 7; i++)
  {
    if (bitRead(pattern_, i) == 0)
    {
      ledcWrite(i, 0);
    }
    else {
      ledcWrite(i, msblsb[i]);
    }
  }
  /*
    digitalWrite(ch1, bitRead(pattern_,0));
    digitalWrite(ch2, bitRead(pattern_,1));
    digitalWrite(ch3, bitRead(pattern_,2));
    digitalWrite(ch4, bitRead(pattern_,3));
    digitalWrite(ch5, bitRead(pattern_,4));
    digitalWrite(ch6, bitRead(pattern_,5));
  */
}


// Sets analogue output in the TLV5618
// channel is either 0 ('A') or 1 ('B')
// value should be between 0 and 4095 (12 bit max)
// pins should be connected as described above
/*void analogueOut(int channel, byte msb, byte lsb)
  {
  digitalWrite(latchPin, LOW);
  msb &= B00001111;
  if (channel == 0)
     msb |= B10000000;
  // Note that in all other cases, the data will be written to DAC B and BUFFER
  shiftOut(dataPin, clockPin, MSBFIRST, msb);
  shiftOut(dataPin, clockPin, MSBFIRST, lsb);
  // The TLV5618 needs one more toggle of the clockPin:
  digitalWrite(clockPin, HIGH);
  digitalWrite(clockPin, LOW);
  digitalWrite(latchPin, HIGH);
  }
*/


/*
  // This function is called through an interrupt
  void triggerMode()
  {
  if (triggerNr_ >=0) {
    PORTB = triggerPattern_[sequenceNr_];
    sequenceNr_++;
    if (sequenceNr_ >= patternLength_)
      sequenceNr_ = 0;
  }
  triggerNr_++;
  }


  void blankNormal()
  {
    if (DDRD & B00000100) {
      PORTB = currentPattern_;
    } else
      PORTB = 0;
  }

  void blankInverted()
  {
   if (DDRD & B00000100) {
     PORTB = 0;
   } else {
     PORTB = currentPattern_;
   }
  }

*/

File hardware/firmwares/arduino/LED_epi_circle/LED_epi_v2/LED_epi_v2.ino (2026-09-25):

#include <FastLED.h>
#include <Encoder.h>

// LED set up
#define LED_PIN        6        // LED Data In PIN
#define NUM_LEDS       16       // LED number
#define BRIGHTNESS     32       // Startup brightness
#define MAX_BRIGHTNESS 255       // Max brightness (limit 255)
#define LED_TYPE       WS2812B  // LED type
#define COLOR_ORDER    GRB      // Colours order

// Encoder pins
#define ENCODER_PIN_A  2
#define ENCODER_PIN_B  3
#define ENCODER_BUTTON 4

// Modes
#define MODE_MOVE       0
#define MODE_BRIGHTNESS 1
#define MODE_LENGTH     2

CRGB leds[NUM_LEDS];
Encoder myEncoder(ENCODER_PIN_A, ENCODER_PIN_B);

// Variables for tracking
long oldPosition = 0;      // Previous encoder position
int segmentLength = NUM_LEDS;     // Length of illuminated segment
int currentPosition = 0;   // Current position of the first LED in segment
int currentMode = MODE_BRIGHTNESS; // Current operating mode
int currentBrightness = BRIGHTNESS; // Current brightness level
bool ledsOn = true;        // Flag for LEDs on/off state

// Colors for different modes
CRGB moveColor = CRGB::White;      // Color when in movement mode
CRGB brightnessColor = CRGB::White; // Color when in brightness mode
CRGB lengthColor = CRGB::Yellow;     // Color when in length mode

// Button handling variables
int buttonState = HIGH;     // Current button state
int lastButtonState = HIGH; // Previous button state
unsigned long lastDebounceTime = 0;  // Last debounce time
unsigned long debounceDelay = 50;    // Debounce time in ms

// Double-click detection
unsigned long lastClickTime = 0;
unsigned long doubleClickDelay = 300; // Max time between clicks to count as double-click
bool awaitingDoubleClick = false;

// Long press detection
unsigned long buttonPressStart = 0;
bool longPressHandled = false;
unsigned long longPressDuration = 1000; // seconds for long press

void setup() {
  // Initialize FastLED
  FastLED.addLeds<LED_TYPE, LED_PIN, COLOR_ORDER>(leds, NUM_LEDS)
    .setCorrection(TypicalLEDStrip);
  FastLED.setBrightness(currentBrightness);
  
  // Set up button with internal pull-up resistor
  pinMode(ENCODER_BUTTON, INPUT_PULLUP);
  
  // Initialize serial for debugging
  Serial.begin(9600);
  Serial.println("Starting LED ring control with encoder");
  Serial.println("Default mode: Brightness adjustment");
  Serial.println("Single click: Segment move");
  Serial.println("Double click: Segment length adjustment");
  Serial.println("Long press (1s): Turn LEDs on/off");
  
  // Initial LED update
  updateLEDs();
}

void loop() {
  // Only process encoder if LEDs are on
  if (ledsOn) {
    // Read encoder position (divide by 4 to reduce sensitivity)
    long newPosition = myEncoder.read() / 4;
    
    // Check if position has changed
    if (newPosition != oldPosition) {
      switch (currentMode) {
        case MODE_MOVE:
          // MOVE SEGMENT MODE
          if (newPosition > oldPosition) {
            // Clockwise rotation - move segment forward
            currentPosition = (currentPosition + 1) % NUM_LEDS;
          } else {
            // Counter-clockwise rotation - move segment backward
            currentPosition = (currentPosition - 1 + NUM_LEDS) % NUM_LEDS;
          }
          Serial.print("Position: ");
          Serial.println(currentPosition);
          break;
          
        case MODE_BRIGHTNESS:
          // BRIGHTNESS ADJUSTMENT MODE
          if (newPosition > oldPosition) {
            // Increase brightness (max is MAX_BRIGHTNESS)
            currentBrightness = min(currentBrightness + 2, MAX_BRIGHTNESS);
          } else {
            // Decrease brightness (min is 2)
            currentBrightness = max(currentBrightness - 2, 2);
          }
          FastLED.setBrightness(currentBrightness);
          Serial.print("Brightness: ");
          Serial.println(currentBrightness);
          break;
          
        case MODE_LENGTH:
          // SEGMENT LENGTH MODE
          if (newPosition > oldPosition) {
            // Increase segment length (max is NUM_LEDS)
            segmentLength = min(segmentLength + 1, NUM_LEDS);
          } else {
            // Decrease segment length (min is 1)
            segmentLength = max(segmentLength - 1, 1);
          }
          Serial.print("Segment Length: ");
          Serial.println(segmentLength);
          break;
      }
      
      // Update old position
      oldPosition = newPosition;
      
      // Update LEDs
      updateLEDs();
    }
  }
  
  // Button handling for mode switching and power toggle
  int reading = digitalRead(ENCODER_BUTTON);
  
  if (reading != lastButtonState) {
    lastDebounceTime = millis();
  }
  
  if ((millis() - lastDebounceTime) > debounceDelay) {
    if (reading != buttonState) {
      buttonState = reading;
      
      // Button press detected (LOW when using INPUT_PULLUP)
      if (buttonState == LOW) {
        // Button pressed - start timing for long press
        buttonPressStart = millis();
        longPressHandled = false;
      } else {
        // Button released - check if it was a long press
        unsigned long pressDuration = millis() - buttonPressStart;
        
        if (pressDuration >= longPressDuration && !longPressHandled) {
          // Long press detected - toggle LEDs on/off
          ledsOn = !ledsOn;
          Serial.print("LEDs toggled: ");
          Serial.println(ledsOn ? "ON" : "OFF");
          updateLEDs();
          longPressHandled = true;
        } else if (pressDuration < longPressDuration && !longPressHandled) {
          // Short press - handle regular button press
          handleButtonPress();
        }
      }
    }
  }
  
  // Check if we're awaiting a double click and time is up
  if (awaitingDoubleClick && (millis() - lastClickTime > doubleClickDelay)) {
    awaitingDoubleClick = false;
    
    // We had a single click (not a double), so switch to brightness mode
    if (currentMode != MODE_BRIGHTNESS) {
      currentMode = MODE_BRIGHTNESS;
      Serial.println("Mode changed: BRIGHTNESS ADJUSTMENT");
      updateLEDs();
    } else {
      // If already in brightness mode, go back to move mode
      currentMode = MODE_MOVE;
      Serial.println("Mode changed: MOVE SEGMENT");
      updateLEDs();
    }
  }
  
  lastButtonState = reading;
}
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

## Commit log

2026-09-21 21.09.2026: README update
    [Basler_ROE200-COM3_Arduino32Bit-COM5_laser-presets.cfg]
2026-09-23 23.09.2026: add ArduinoMM
    [Basler_ROE200-COM3_Arduino-COM5.cfg, Basler_ROE200-COM3_Arduino-COM5_laser-presets.cfg]
2026-09-25 25.09.2026: add holders models
    [01.csv, 02.csv, 03.csv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]
